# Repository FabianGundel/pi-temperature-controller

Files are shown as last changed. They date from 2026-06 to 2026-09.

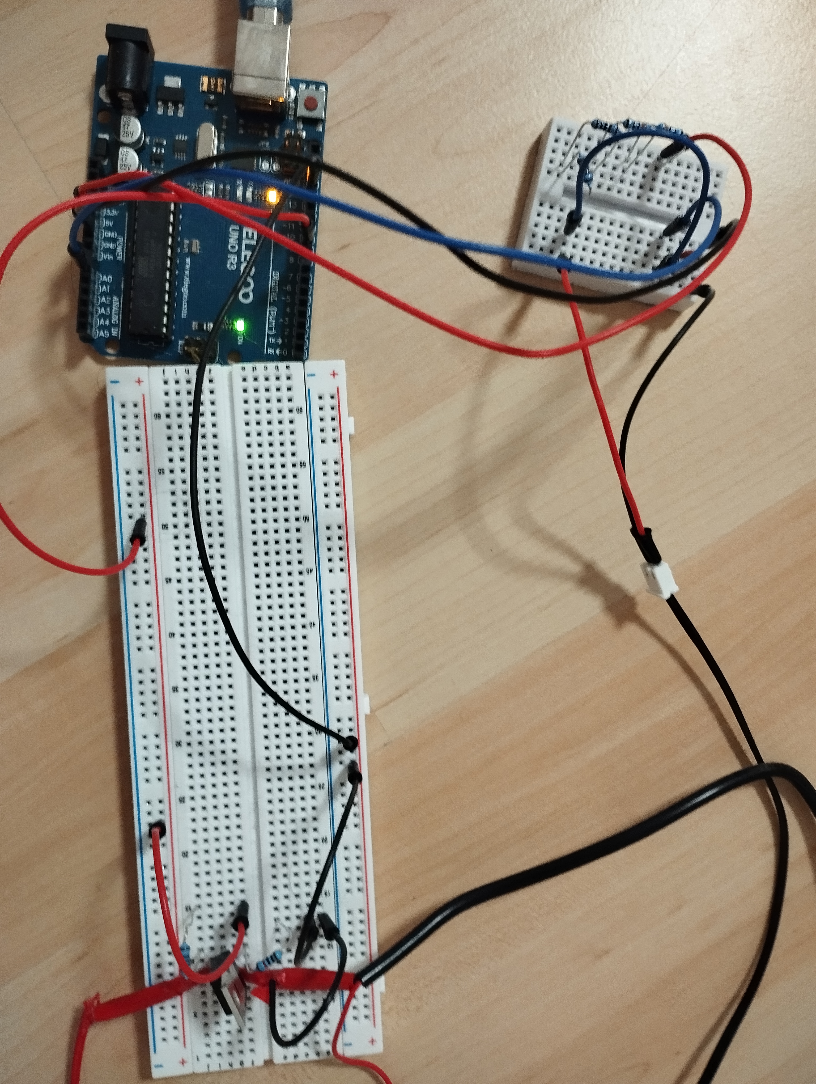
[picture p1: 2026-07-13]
images/electronics.jpg

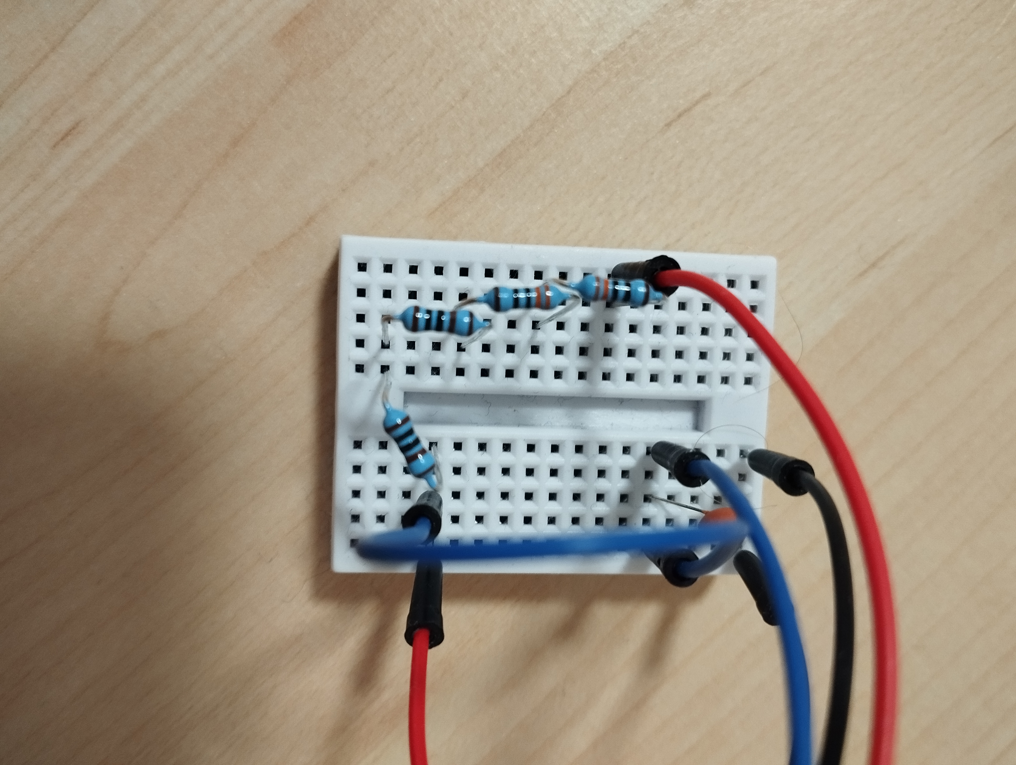
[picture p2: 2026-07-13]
images/measurement.jpg

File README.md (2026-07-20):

# PI Temperature Controller – Water Bath System

---

## Project Overview

This project is a self-developed **PI-based temperature control system** for a water bath, implemented using an Arduino UNO.

> First a PID-Controller was tried to be implemented, but after some 
> development time and research the D-Part of the controller came out to be 
> unnecessary and was thrown out.

The goal is precise temperature regulation of a 1L water container using a self-calibrated NTC thermistor and a PWM-controlled heating element.

This project is being built to better understand practical control engineering, temperature measurement, PWM power control and sensor calibration. Instead of using a ready-made thermostat module, the entire control loop is being implemented using an Arduino UNO, a MOSFET-driven heating element, and a self-calibrated NTC thermistor.

---

## Project Objectives

- Design and implementation of a closed-loop control system
- Development of a PI control algorithm
- Calibration of an NTC temperature sensor [NTC-Calibration](docs/calibration.md)
- Implementation of PWM-based power control

---

## Hardware

[Hardware](hardware/pi-temperature-controller-hardware.pdf)

---

## Circuit

[Main Circuit Diagram](docs/main.pdf)

[Images](images/)

> A 100nF decoupling capacitor was added between A0 and GND
> to filter high-frequency noise on the ADC input.

---

## PI-Controller

The System got calibrated on heating the water up to 35°C and holding the tempearture there consistently.

[Temperature Curve Image](images/PI-Curve.png)

[PI-Documentation](docs/pi.md)

---

## Code

[PI-Temperature-Regulation Code](src/main/main.ino)

---

## System Architecture

### 1. Temperature Measurement
- Waterproof 10kΩ NTC thermistor (25°C reference)
- 2660Ω reference resistor
- Temperature calculation using the Steinhart–Hart equation

### 2. Signal Processing
- Arduino UNO microcontroller
- Real-time temperature computation
- Error calculation (setpoint vs. measured value)
- PI control algorithm

### 3. Power Stage
- MOSFET: IRLB8743
- PWM-controlled switching
- Heating element: 12V / 40W epoxy-sealed heater
- Power supply: 12V / 60W

### 4. Actuator
- Immersed heating element inside the water bath

---

## Current Status

✔ Hardware fully assembled 
✔ MOSFET successfully tested 
✔ NTC sensor calibrated 
✔ Temperature measurement functional 
✔ Control algorithm implemented
✔ PI parameter tuning finished

---

## Tools

> These tools were built with AI assistance and are provided
> as-is for development use. The core PI implementation
> in src/ was developed and understood independently.

The PI tuning process requires observing temperature curves over
several minutes. The Arduino Serial Plotter resets its time axis
on each reconnect and offers no export functionality.

- [Server](tools/host/localhost-pid-data.py): lightweight local server that receives and stores
  incoming temperature data
  
- [Uploader](tools/upload/serial-to-localhost.py): reads Serial output from the Arduino and forwards
  it to the server
  
- [Visualizer](tools/plotter/plotter.py): plots the live temperature curve with a
  time axis for better readability on slow thermal systems 

---

## License

MIT

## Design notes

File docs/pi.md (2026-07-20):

# PI Controller – Implementation & Tuning

## Control Architecture

A closed-loop feedback system where the controller continuously adjusts
PWM output based on the difference between setpoint and measured temperature.

---

## Why PI and not PID

A D-term was initially implemented but removed during tuning for two reasons:

- The water bath is a thermally slow system – temperature changes over
  seconds, not milliseconds. The D-term had no meaningful signal to act on.
- The NTC ADC signal contains residual noise even after capacitor filtering.
  The D-term amplified this noise, causing erratic PWM output.

A PI controller proved sufficient for stable and precise temperature regulation.

---

## Control Terms

**P – Proportional**
Drives output proportional to the current error. Provides the main
heating power during warm-up but cannot eliminate steady-state offset alone.

**I – Integral**
Accumulates error over time and eliminates steady-state offset.
Becomes the dominant term once the system approaches the setpoint.

---

## Challenges during parameter tuning

During the tuning process, some anomalies occurred that required the implementation of further elements into the basic PI-Controller to solve those problems.

### Feedforward Offset

At the target temperature of 35°C the system requires approximately
150/255 PWM just to compensate for heat loss to the environment.
A standard PI controller would need to accumulate a large integral
term to provide this base load, causing slow response and overshoot.

To solve this, a fixed feedforward offset is added directly to the
controller output:

```cpp
rawOutput = offset + (Kp * errorPid) + (Ki * integral);
```

This allows the PI controller to operate only around the deviation
from the steady-state operating point, enabling much smaller Kp and
Ki values and significantly reducing integral windup.

### Anti-Windup

The integral term is only active within a defined error threshold
around the setpoint:

```cpp
if (abs(errorPid) < integralCap) {
    integral += errorPid * dt;
}
```

During the heating phase, the proportional term and feedforward offset
provide sufficient output to drive the temperature toward the setpoint.
Accumulating the integral during this phase would cause significant
overshoots once the setpoint is reached.

By activating the integral only within the threshold, it starts from
zero when the system enters the fine control region – eliminating the
steady-state offset left by the P-term without the risk of windup.

---

## Tuning

Tuning was performed by observing the temperature response curve using
a [custom live visualizer](../../tools/plotter/plotter.py).

### Approach

Starting point: Kp high enough to reach setpoint, Ki = 0.

Ki was increased gradually until a steady-state offset was eliminated
without significant overshoot.

### Final Parameters

| Parameter | Value |
|---|---|
| Kp | 18.0  |
| Ki | 0.01  |

---

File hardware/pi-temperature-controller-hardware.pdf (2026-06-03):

Component | Model/Specification | Quantity | Notes
Microcontroller | Arduino UNO | 1 | -
Temperature Sensor [TH1] | 10K Waterproof NTC | 1 | -
Reference Resistor [R1] | 2660R | 1 | -
Gate Resistor [R2] | 100R | 1 | -
Pull-Down Resistor [R3] | 10K | 1 | -
Power MOSFET [Q1] | IRLB8743 | 1 | -
Heating Element [H1] | 12V/40W | 1 | Epoxy sealed
Capacitor [C1] | Ceramic; 100nF | 1 | -
Power Supply | 12V/60W | 1 | -
Breadboard | Standart | 1 | -
Jumper Wires | - | Set | -
Water Container | 1L; Glass | 1 | -

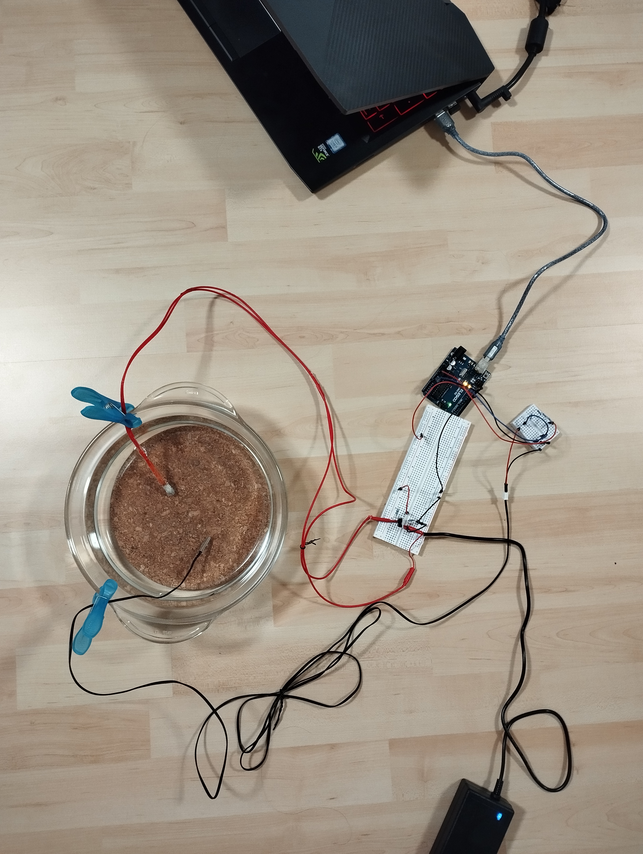
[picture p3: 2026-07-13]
images/whole.jpg

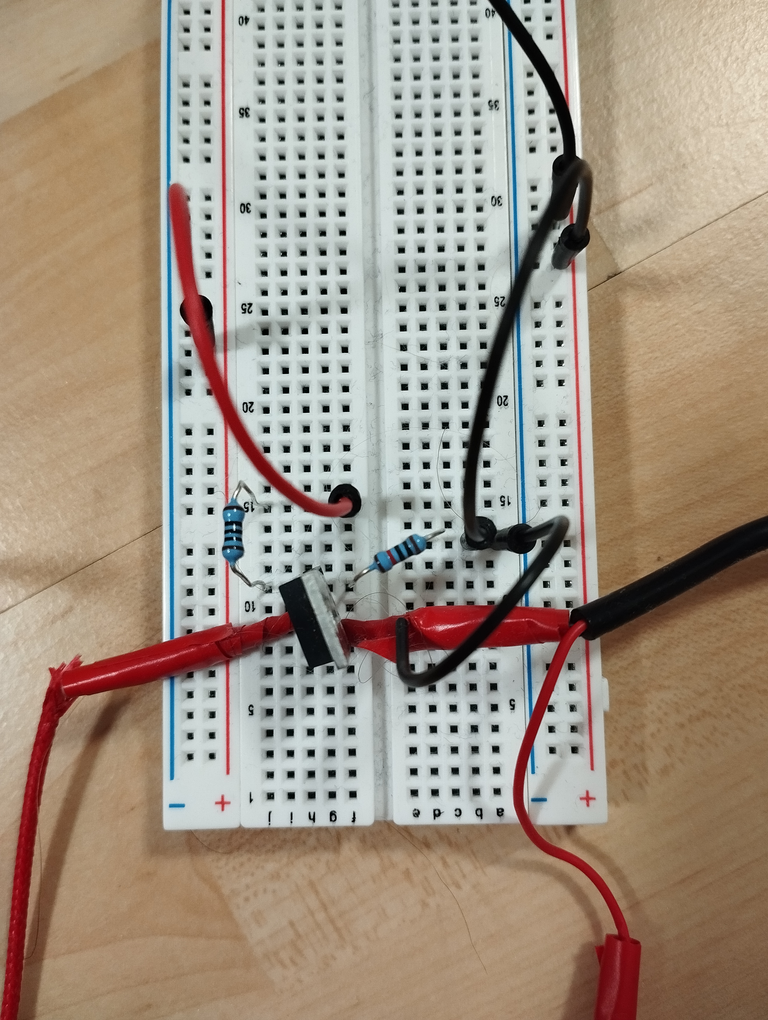
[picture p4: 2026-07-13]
images/controll.jpg

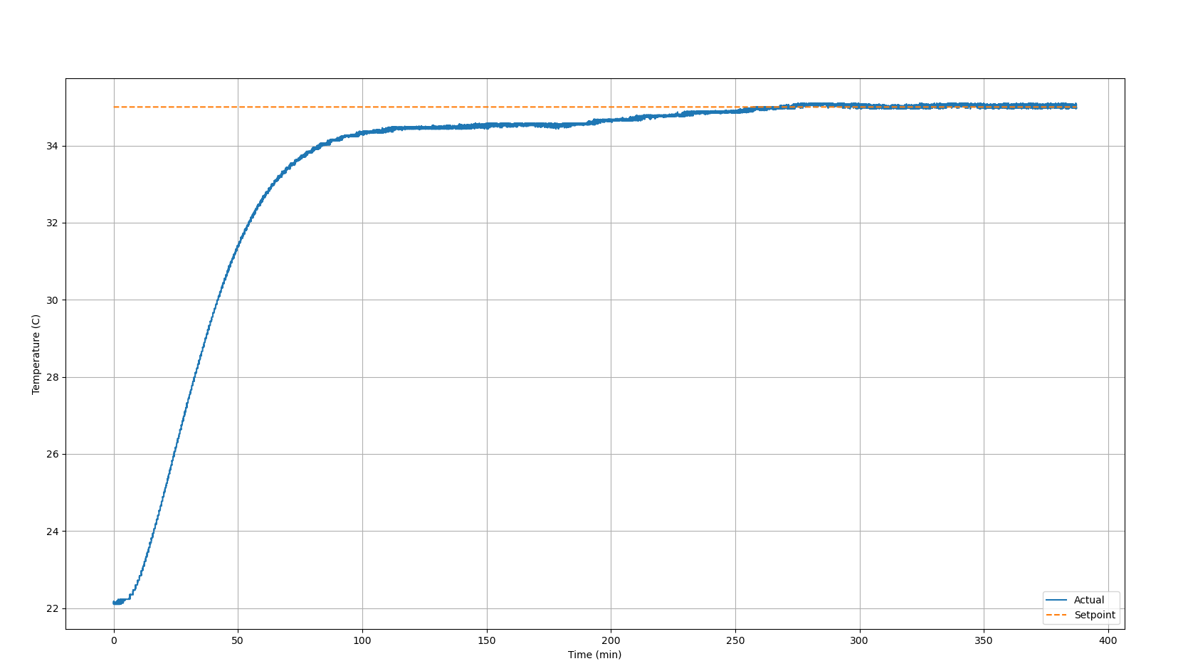
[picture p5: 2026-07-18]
images/PI-Curve.png

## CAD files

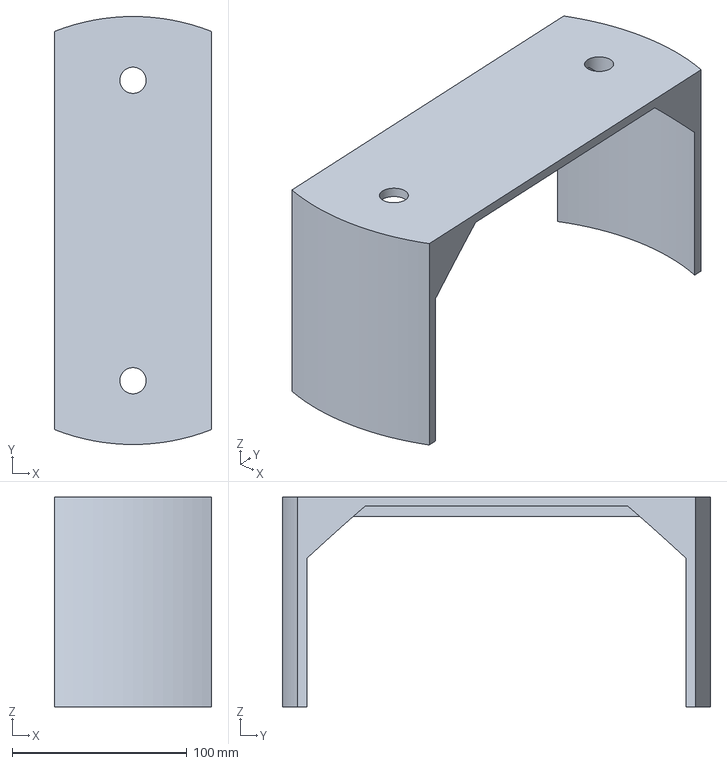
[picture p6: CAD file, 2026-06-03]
cad/mounting_bracket.FCStd
90.0 x 245.0 x 120.0 mm

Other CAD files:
cad/mounting_bracket.stl

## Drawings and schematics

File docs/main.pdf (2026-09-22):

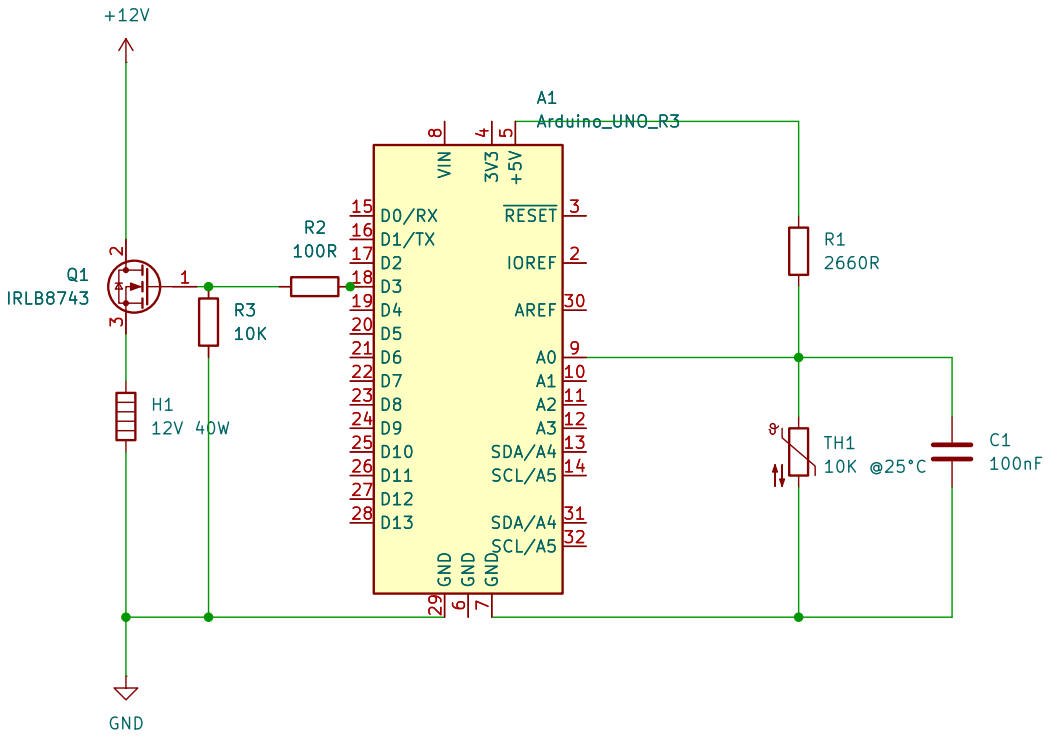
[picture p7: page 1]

Sheet: /
File: main.kicad_sch
Title: pid-temperature-controller|main

Size: A4 | Rev: v1.3
KiCad E.D.A. 10.0.3 | Id: 1/1

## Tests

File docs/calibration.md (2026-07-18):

# NTC Thermistor Calibration

Calibration of a NTC thermistor using the Steinhart-Hart equation for the water bath PI controller.

## Components

- NTC Thermistor: 10kΩ @ 25°C
- Reference resistor: 2660Ω
- Arduino Uno
- Reference thermometer

---

## Circuit

[Calibration Circuit Diagram](../docs/calibration.pdf)

---
 
## Code

[Calibration Code](../src/calibration/calibration.ino)

---

## Calibration Data

| T (°C) | avg ADC Raw | R_NTC (Ω) |
|---|---|---|
| 25.0 | 808.1 | 10000 |
| 61.8 | 456.8 |  2146 |
| 85.5 | 280.0 |  1002 |

---

## Steinhart-Hart Coefficients

The coefficients were calculated from three reference temperature points
using nonlinear curve fitting based on the Steinhart-Hart model.

Calculated using the [Thermistor Calculator by Stanford Research Systems Inc](https://www.thinksrs.com/downloads/programs/therm%20calc/ntccalibrator/ntccalculator.html)
> **Note:** If the link is unavailable, coefficients can be recalculated using any
> Steinhart-Hart solver using the calibration data.

| Coefficient | Value |
|---|---|
| A | 0.7215939276e-3 |
| B | 3.161853033e-4  |
| C | -3.580517355e-7 |

## Formula

1/T = A + B·ln(R) + C·ln(R)³

---

## Results

- Max. deviation: ±0.5°C in the range 20–90°C
- Used ADC range: 254-842

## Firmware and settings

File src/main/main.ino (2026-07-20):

//pid parameter
double Kp = 18.0;
double Ki = 0.01;

double offset = 160.0;
double integralCap = 0.5;

//temperature
double setpoint = 35.0; // °C (<= 90°C !!!)
const int NUM_READS = 5;
const double TEMP_MAX = 95.0;

//steinhart-hart
const double A = 0.0007215939276;
const double B = 0.0003161853033;
const double C = -0.0000003580517355;

//hardware
const int PIN_NTC = A0;
const int PIN_MOSFET = 9;

const double V_REF = 5.0;
const double R_REF = 2660.0;

//intern

double temperature = 0.0;
double lastPrintedTemp = 0.0;

double errorPid = 0.0;
double previousError = 0.0;

double integral = 0.0;
double derivative = 0.0;

double rawOutput = 0.0;
double output = 0.0;

unsigned long previousTime = 0;


//setup

void setup() {

  Serial.begin(9600);

  pinMode(PIN_MOSFET, OUTPUT);

  analogWrite(PIN_MOSFET, 0.0);

  previousTime = millis();

  Serial.println("PID Temperaturcontroller gestartet");
}

//loop
void loop() {

  //time
  unsigned long currentTime = millis();
  double dt = (currentTime - previousTime) / 1000.0;

  if (dt <= 1.0) return;

  previousTime = currentTime;

  temperature = readTemperature();

  //safety cutoff
  if (temperature > TEMP_MAX) {
    Serial.println("WARNING: Temperature is too high!");
    while (true) {
      analogWrite(PIN_MOSFET, 0);
    } 
  }

  //error calc 
  errorPid = setpoint - temperature;

  //integral & anti-windup 
  if (abs(errorPid) < integralCap) { 
    integral += errorPid * dt;
  }
      
  //pid calc
  rawOutput = offset + (Kp * errorPid) + (Ki * integral);
  
  previousError = errorPid;

  //pwm output
  output = constrain(rawOutput, 0, 255);

  analogWrite(PIN_MOSFET, output);

  //serial output
  Serial.println("ADC: " + String(analogRead(A0)));
  Serial.println("Setpoint: " + String(setpoint) + "°C");
  Serial.println("Process: " + String(temperature) + "°C");
  Serial.println("PWM: " + String(output));
  Serial.println("Error: " + String(errorPid));
  Serial.println("Proportional: " + String(errorPid * Kp));
  Serial.println("Integral: " + String(integral * Ki));
  Serial.println("---------------------------------------");
}


//temperature measurement
double readTemperature() {

  long sum = 0;
  for (int i = 0; i < NUM_READS; i++) {
    sum += analogRead(PIN_NTC);
    delay(10);
  }
  float adc_avg = (float)sum / NUM_READS;

  adc_avg = constrain(adc_avg, 1, 1022);

 
  double voltage =
    (adc_avg * V_REF) / 1023.0;

 
  double ntcResistance =
  R_REF * voltage / (V_REF - voltage);

 
  double lnR = log(ntcResistance);

  double temperatureKelvin =
    1.0 / (A + (B * lnR) + (C * lnR * lnR * lnR));

  double temperatureCelsius = temperatureKelvin - 273.15;

  return temperatureCelsius;
}

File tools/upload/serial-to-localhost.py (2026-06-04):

import serial
import requests

SERVER_URL = "" #localhostURL + /data
BAUD_RATE = 9600 
COM_PORT = "COM4" #Change to your COM port

ser = serial.Serial(COM_PORT, BAUD_RATE)

while True:
    line = ser.readline().decode().strip()

    requests.post(
        SERVER_URL,
        json={"value": line}
    )

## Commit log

2026-05-09 add calibration documentation
2026-05-11 added hardware files & removed dead links
    [pid-temperature-controller-hardware.xlsx]
2026-05-12 add calibration code & link
2026-05-13 add main/calibration circuit diagram & links
    [calibration.kicad_sch, main.kicad_sch]
2026-05-13 edit components & main circuit
    [main.kicad_sch, pid-temperature-controller-hardware.xlsx]
2026-05-19 add empty pid.md
2026-06-03 updated hardware
    [main.kicad_sch, pid-temperature-controller-hardware.xlsx]
2026-06-03 spelling in hardware
    [pid-temperature-controller-hardware.xlsx]
2026-06-03 add cad && mounting bracket
    [mounting_bracket.FCStd, mounting_bracket.stl]
2026-06-04 add python plotter for pid
2026-07-12 formal finish
    [pi-temperature-controller-hardware.xlsx]
2026-07-13 offset & changed para
2026-07-14 changed para
2026-07-14 kp & offset fix, ki ongoing
    [main.ino]
2026-07-14 main.ino comment error calc
    [main.ino]
2026-09-22 correcting main.kicad_sch
    [main.kicad_sch]
